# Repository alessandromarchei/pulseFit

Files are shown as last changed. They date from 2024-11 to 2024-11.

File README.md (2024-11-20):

# PulseFit - Wearable ECG Sensor and Fitness Tracker

**PulseFit** is a compact, energy-efficient, and wearable ECG monitoring device designed for sports and fitness enthusiasts. The project integrates cutting-edge hardware, efficient circuit design, and robust BLE communication to deliver real-time heart rate monitoring in an easy-to-use format. The device is ideal for users looking to track their cardiovascular health during physical activity.

---

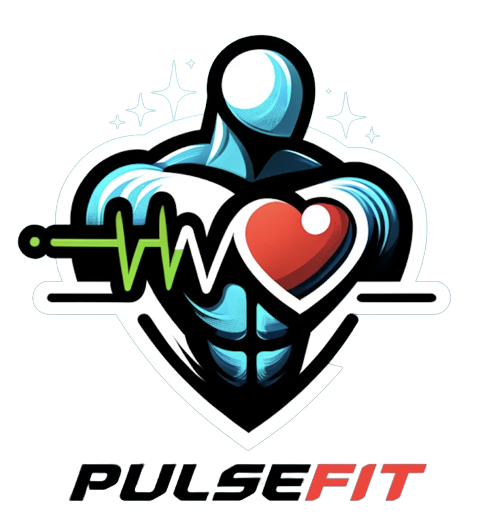
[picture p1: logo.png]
PulseFit


## **Table of Contents**
1. [Project Overview](#project-overview)
2. [Key Features](#key-features)
3. [System Overview](#system-overview)
4. [Hardware Components](#hardware-components)
   - [ECG Sensor](#ecg-sensor)
   - [Microcontroller](#microcontroller)
   - [Power Management](#power-management)
   - [Peripherals](#peripherals)
5. [PCB Design](#pcb-design)
6. [Power Consumption Analysis](#power-consumption-analysis)
7. [Bill of Materials (BOM) and Cost](#bill-of-materials-bom-and-cost)
8. [Usage Instructions](#usage-instructions)
9. [Development and Design History](#development-and-design-history)
10. [Contributors](#contributors)

---

## **Project Overview**
PulseFit is a wearable chest strap designed to monitor ECG signals and transmit data wirelessly to a connected device. The device leverages an **AD8232 ECG sensor** for accurate biopotential signal acquisition and a **CC2640 microcontroller** for data processing and BLE communication. With a battery life of over 40 hours, PulseFit balances functionality, portability, and cost, making it ideal for fitness tracking.

---

## **Key Features**
- **Advanced ECG Monitoring**: High-gain AD8232 sensor tailored for real-time heart rate analysis.
- **BLE Communication**: Integrates BLE 5.0 for seamless data transmission to smartphones or fitness devices.
- **Compact and Lightweight**: PCB dimensions of 5.1 x 2.39 cm, designed for user comfort.
- **Rechargeable and Sustainable**: LiPo battery with USB charging, providing up to 40 hours of use on a single charge.
- **User Feedback**: RGB and charge status LEDs for clear device status indication.
- **Robust Design**: Operates efficiently in extreme environments (-40°C to +85°C).

---

## **System Overview**
The PulseFit system includes the following subsystems:
1. **Signal Acquisition**:
   - Captures ECG signals using the AD8232 sensor.
   - Optimized for minimal interference and high signal integrity.
2. **Data Processing**:
   - Processes signals with the CC2640 ARM Cortex-M3 microcontroller.
   - Converts analog signals to digital values for BLE transmission.
3. **Power Management**:
   - Voltage regulator (**MAX1759EUB**) adapts battery voltage to 3.3V.
   - LiPo battery with USB recharging and thermal protection.
4. **User Interaction**:
   - RGB LED for operational feedback and Red/Green LEDs for charge status.
5. **Wireless Communication**:
   - A 2.4 GHz BLE antenna ensures efficient and reliable data transmission.

---

## **Hardware Components**
### **ECG Sensor**
- **Model**: AD8232
- **Purpose**: Captures biopotential signals with minimal interference.
- **Configuration**: "Next-to-Heart" mode for enhanced cardiac signal strength.
- **Specifications**:
  - Low supply current: 170µA
  - Shutdown mode: 40nA
  - Integrated right-leg drive amplifier
  - High CMRR: 80 dB
- **Advantages**: Compact design with minimal external components for noise reduction.

### **Microcontroller**
- **Model**: CC2640 (Texas Instruments)
- **Core**: ARM Cortex-M3 @ 48 MHz.
- **Features**:
  - Integrated BLE 5.0 controller.
  - Ultra-low power standby mode (1.5µA).
  - Analog-to-Digital Converter (ADC) for ECG signal processing.
- **I/O**:
  - Dedicated GPIO for RGB LEDs and ECG sensor control.
  - JTAG interface for debugging.

### **Power Management**
- **Battery**: LP402025 LiPo (150mAh).
- **Charger**: MCP73831 USB charger with constant-current/voltage control.
- **Voltage Regulator**: MAX1759EUB for stable 3.3V output.
- **LED Indicators**:
  - Red: Charging.
  - Green: Fully charged.

### **Peripherals**
- **Electrodes**: Gold-plated, dry electrodes for superior signal quality and durability.
- **Antenna**: 2.4 GHz patch antenna for BLE communication.
- **Buttons**: Reset button and power slide switch.

---

## **PCB Design**
### **Layout Highlights**
- **Dimensions**: 5.1 x 2.39 cm.
- **Component Placement**:
  - Antenna positioned for minimal interference.
  - ECG sensor placed close to the microcontroller for short signal paths.
  - Power components grouped together for efficient routing.
- **Routing**:
  - Trace width: 0.25 mm to minimize impedance.
  - Class 5C compliance for manufacturing standards.
- **Ground Plane**:
  - Provides noise shielding for critical components.

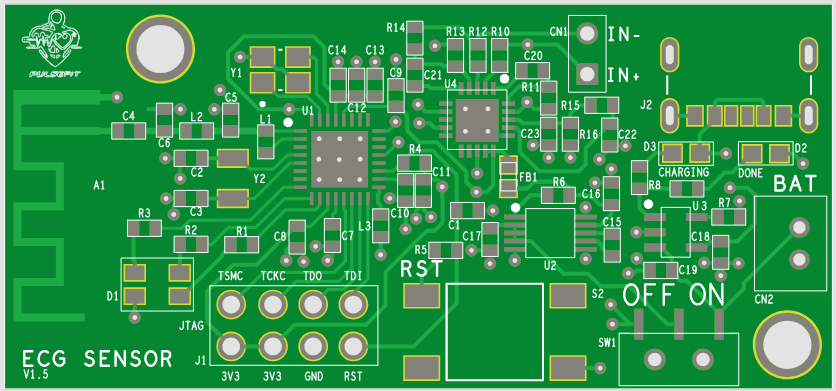
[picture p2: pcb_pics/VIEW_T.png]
Top View of the PCB

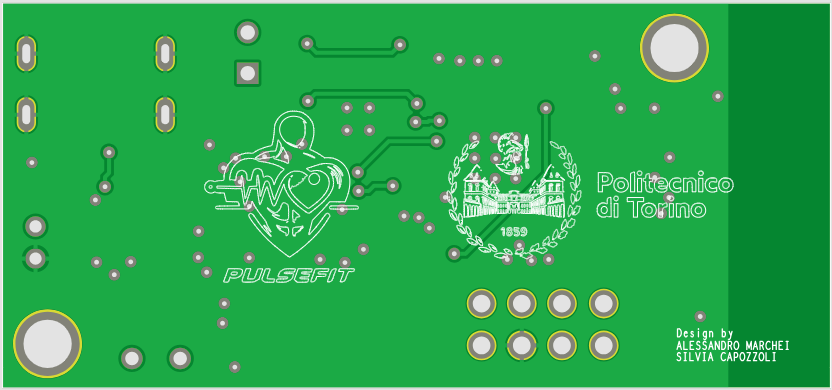
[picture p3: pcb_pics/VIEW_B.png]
Bottom View of the PCB


---

## **Power Consumption Analysis**
Average power consumption:
- **Microcontroller**: 3.02mA.
- **ECG Sensor**: 0.17mA.
- **RGB LEDs**: 0.51mA.
- **Estimated Battery Life**: ~40 hours (150mAh battery).

---

## **Bill of Materials (BOM) and Cost**
### **Cost Breakdown**
| Quantity | PCB (€) | Components (€) | Electrodes (€) | Stencil (€) | Total (€) |
|---|---|---|---|---|---|
| 1 | 38.83 | 30.58 | 18.20 | - | 87.61 |
| 10 | 6.84 | 24.52 | 18.20 | - | 49.56 |
| 100 | 1.80 | 19.38 | 18.20 | 0.33 | 39.71 |
| 1000 | 0.74 | 19.38 | 18.20 | 0.033 | 38.35 |

---

## **Usage Instructions**
1. **Setup**:
   - Charge the device via USB.
   - Attach the chest strap securely with electrodes in place.
2. **Operation**:
   - Power on using the slide switch.
   - Observe RGB LED indicators for device status.
   - Pair with a BLE-compatible device to monitor ECG data.
3. **Maintenance**:
   - Clean electrodes after use.
   - Recharge battery as needed.

In this project, the main files are the following:

- A **project** directory with 2 subfolders : 
	- "Temp" directory contains the entire project, both the Capture project and the Allegro board

	- "ORCAD_PERSONAL_LIBRARY" contains every .OLB for the schematic libraries, every footprint contained in the board and relative .psm in the subfolder "FOOTPRINTS" and every padstack (.pad) in the "PADSTACK" folder.

- The **REPORT** of the project (.pdf)

- The **BOM** containing every cost related to the device, with every price based on the purchase quantity (.xslx)

- The **video demo** of the project (.mp4)

- **Slides** of the video demo (.pdf)

---

## **Development and Design History**
### **Version Highlights**
- **v1.1**: Initial schematic and PCB design.
- **v1.2**: Introduced slide switch for improved usability.
- **v1.3**: Optimized electrode connectivity.
- **v1.4**: Improved component spacing and reduced manufacturing costs.
- **v1.5**: Added mounting holes for secure casing attachment.

---

## **Contributors**
- [Alessandro Marchei](https://github.com/alessandromarchei)
- Silvia Capozzoli

For full documentation and design files, please refer to the `docs` folder, which contains the 'pulsefit.pdf' for the entire report documenting the purpose and details of the entire project.

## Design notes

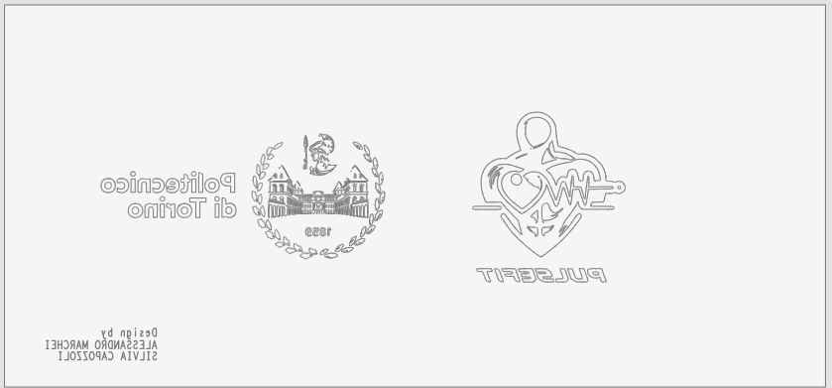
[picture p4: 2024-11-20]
pcb_pics/LEGEND_B.png

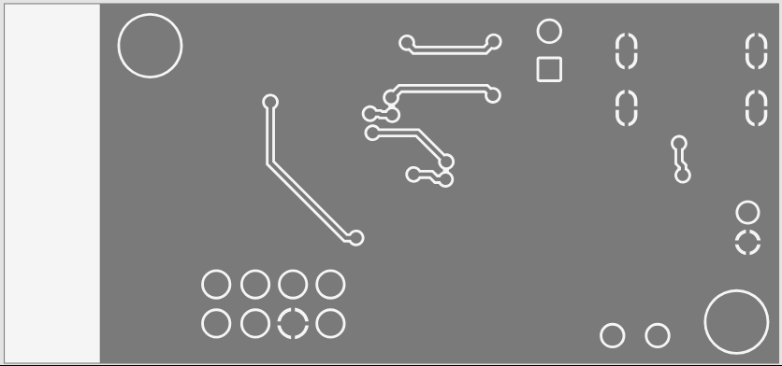
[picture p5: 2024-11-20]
pcb_pics/COPPER_B.png

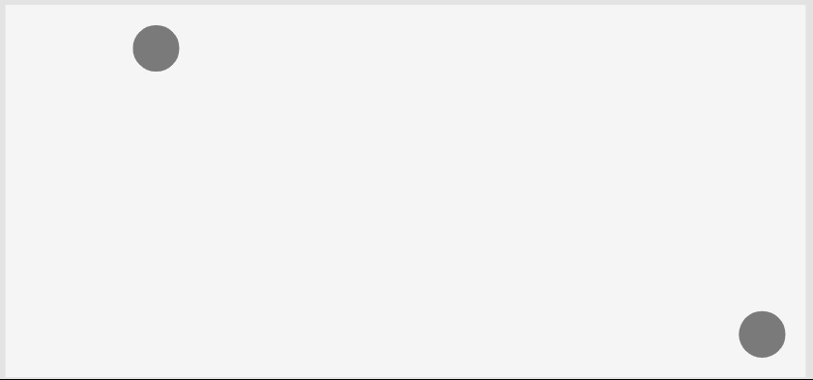
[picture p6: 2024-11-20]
pcb_pics/NON_PLATED_DRILL.png

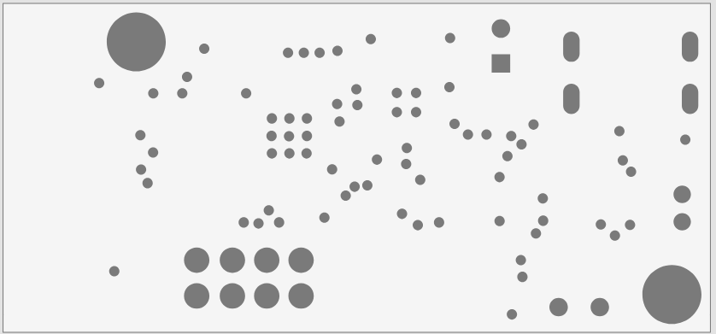
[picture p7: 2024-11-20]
pcb_pics/SMASK_B.png

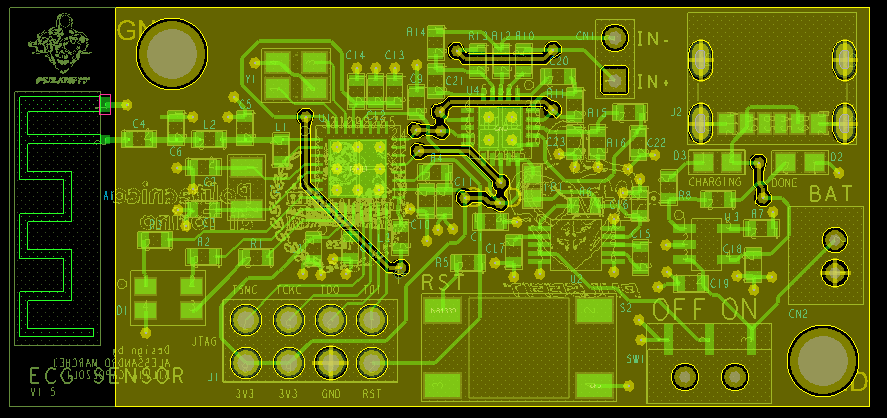
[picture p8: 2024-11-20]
pcb_pics/PCB_BOTTOM.png

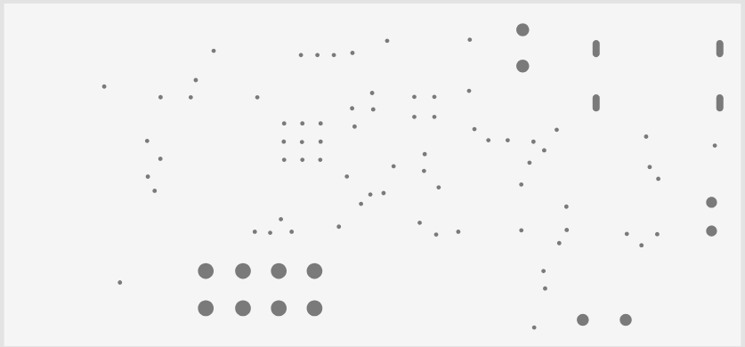
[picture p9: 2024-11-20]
pcb_pics/PLATED_DRILL.png

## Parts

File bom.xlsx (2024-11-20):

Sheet: 1
ITEM | QTY | REFERENCE | PART | COMPONENT | MOUNTING TYPE | MANUFACTURER | SUPPLIER | UNIT PRICE
1 | 1 | A1 | ANTENNA | / |  |  | /
2 | 1 | CN1 | 2x HEADER | 3-644456-2 | TH | TE Connectivity AMP Connectors | Digikey | 0.1800 €
3 | 1 | CN2 | JST-2P | B2B-PH-K-S | TH | JST Sales America Inc. | Digikey | 0.1700 €
4 | 3 | C2,C3,C4 | 12 pF | 600S120GT250XT | SMD | Amercian Technical Ceramics | Digikey | 1.0500 €
5 | 2 | C5,C6 | 1.2 pF | QSCP251Q1R2B1GV001T | SMD | Johanson Technology | Digikey | 0.2000 €
6 | 1 | C7 | 1 uF | CL10B105KA8NNNC | SMD | Samsung Electro-Mechanics | Digikey | 0.0900 €
7 | 5 | C1,C8,C9,C11,C13,C14 | 100 nF | CL10B104KA8NNNC | SMD | Samsung Electro-Mechanics | Digikey | 0.0900 €
8 | 3 | C10,C12,C16 C17 | 10 uF | CL10A106MA8NRNC | SMD | Samsung Electro-Mechanics | Digikey | 0.2400 €
9 | 1 | C15 | 0.33 uF | CL10B334KA8VPNC | SMD | Samsung Electro-Mechanics | Digikey | 0.1300 €
10 | 2 | C18,C19 | 4.7uF | CL10A475MA8NQNC | SMD | Samsung Electro-Mechanics | Digikey | 0.2500 €
11 | 1 | C20 | 0.22uF | CC0603KRX7R9BB224 | SMD | YAGEO | Digikey | 0.2600 €
12 | 1 | C21 | 1nF | AC0603JRNPO0BN102 | SMD | YAGEO | Digikey | 0.1500 €
13 | 2 | C22,C23 | 0.1uF | CC0603MRX7R9BB104 | SMD | YAGEO | Digikey | 0.0900 €
14 | 1 | D1 | RGB | XZM2CRKM2DGFBB45SCCB | SMD | SunLED | Digikey | 0.9300 €
15 | 2 | D2,D3 | LED | LTST-S270KGKT | SMD | Lite-On Inc. | Digikey | 0.2200 €
16 | 1 | J1 | 4X2 MALE HEADER | 61300821121 | TH | Würth Elektronik | Digikey | 0.6400 €
17 | 1 | J2 | USB CONNECTOR | UJC-HP-3-SMT-TR | SMD | CUI Devices | Digikey | 0.9100 €
18 | 1 | L1 | 15 nH | BSPQ0006030415NH00 | SMD | Pulse Electronics | Digikey | 0.1200 €
19 | 1 | L2 | 2 nH | L-14W2N0CV4E | SMD | Johanson Technology Inc. | Digikey | 0.2100 €
20 | 1 | L3 | 10 uH | LQM18DH100M70L | SMD | Murata Electronics | Digikey | 0.2300 €
21 | 2 | R1,R2 | 100 | RC0603JR-07100RL | SMD | YAGEO | Digikey | 0.0900 €
22 | 1 | R3 | 270 | RC0603FR-07270RL | SMD | YAGEO | Digikey | 0.0900 €
23 | 1 | R4 | 10k | RMCF0603FT10K0 | SMD | Stackpole Electronics Inc | Digikey | 0.0900 €
24 | 1 | R5 | 330 | RC0603JR-13330RL | SMD | YAGEO | Digikey | 0.0900 €
25 | 1 | R6 | 100 k | RMCF0603FT100K | SMD | Stackpole Electronics Inc | Digikey | 0.0900 €
26 | 1 | R7 | 8.2 k | RMCF0603FT8K20 | SMD | Stackpole Electronics Inc | Digikey | 0.0900 €
27 | 2 | R8,R9 | 150 | RT0603FRE07150RL | SMD | YAGEO | Digikey | 0.0900 €
28 | 2 | R10,R12 | 180k | ERA-8AEB184V | SMD | Panasonic Electronic Components | Digikey | 0.5400 €
29 | 5 | R11,R13,R14,R15,R16 | 10M | RC0603FR-1310ML | SMD | YAGEO | Digikey | 0.0900 €
30 | 1 | S1 | SPDT | AYZ0102AGRLC | TH | C&K | Digikey | 1.1400 €
31 | 1 | S2 | BUTTON | FSM2JSMA | SMD | TE Connectivity ALCOSWITCH Switches | Digikey | 0.2500 €
32 | 1 | U1 | CC2640R2LRHBR | CC2640R2LRHBR | SMD | Texas Instruments | Digikey | 4.0100 €
33 | 1 | U2 | MAX1759 | MAX1759EUB+ | SMD | Analog Devices Inc./Maxim Integrated | Digikey | 6.8800 €
34 | 1 | U3 | MCP73831 | MCP73831T-2ACI/OT | SMD | Microchip Technology | Digikey | 0.6900 €
35 | 1 | U4 | ECG SENSOR | AD8233 | SMD | Analog Devices Inc. | Digikey | 4.2500 €
36 | 1 | Y1 | 24 MHz | TSX-3225_240000MF20X-AC1 | SMD | Epson | Digikey | 0.3500 €
37 | 1 | Y2 | 32.76 KHz | FC-135R_327680KA-AG1 | SMD | Epson | Digikey | 0.6400 €
38 | 1 | FB1 | 1.5 Kohm @ 100 MHz | BLM18HE152SN1D | SMD | Murata Electronics | Digikey | 0.1700 €
 | TOTAL |  |  |  |  |  |  | 30.5800 €

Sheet: 10
ITEM | QTY | REFERENCE | PART | COMPONENT | MOUNTING TYPE | MANUFACTURER | SUPPLIER | UNIT PRICE
1 | 1 | A1 | ANTENNA | / |  |  | /
2 | 1 | CN1 | 2x HEADER | 3-644456-2 | TH | TE Connectivity AMP Connectors | Digikey | 0.1560 €
3 | 1 | CN2 | JST-2P | B2B-PH-K-S | TH | JST Sales America Inc. | Digikey | 0.1340 €
4 | 3 | C2,C3,C4 | 12 pF | 600S120GT250XT | SMD | Amercian Technical Ceramics | Digikey | 0.7880 €
5 | 2 | C5,C6 | 1.2 pF | QSCP251Q1R2B1GV001T | SMD | Johanson Technology | Digikey | 0.1320 €
6 | 1 | C7 | 1 uF | CL10B105KA8NNNC | SMD | Samsung Electro-Mechanics | Digikey | 0.0360 €
7 | 5 | C1,C8,C9,C11,C13,C14 | 100 nF | CL10B104KA8NNNC | SMD | Samsung Electro-Mechanics | Digikey | 0.0220 €
8 | 3 | C10,C12,C16 C17 | 10 uF | CL10A106MA8NRNC | SMD | Samsung Electro-Mechanics | Digikey | 0.1550 €
9 | 1 | C15 | 0.33 uF | CL10B334KA8VPNC | SMD | Samsung Electro-Mechanics | Digikey | 0.0880 €
10 | 2 | C18,C19 | 4.7uF | CL10A475MA8NQNC | SMD | Samsung Electro-Mechanics | Digikey | 0.1610 €
11 | 1 | C20 | 0.22uF | CC0603KRX7R9BB224 | SMD | YAGEO | Digikey | 0.1660 €
12 | 1 | C21 | 1nF | AC0603JRNPO0BN102 | SMD | YAGEO | Digikey | 0.1010 €
13 | 2 | C22,C23 | 0.1uF | CC0603MRX7R9BB104 | SMD | YAGEO | Digikey | 0.0410 €
14 | 1 | D1 | RGB | XZM2CRKM2DGFBB45SCCB | SMD | SunLED | Digikey | 0.6060 €
15 | 2 | D2,D3 | LED | LTST-S270KGKT | SMD | Lite-On Inc. | Digikey | 0.1210 €
16 | 1 | J1 | 4X2 MALE HEADER | 61300821121 | TH | Würth Elektronik | Digikey | 0.5410 €
17 | 1 | J2 | USB CONNECTOR | UJC-HP-3-SMT-TR | SMD | CUI Devices | Digikey | 0.7610 €
18 | 1 | L1 | 15 nH | BSPQ0006030415NH00 | SMD | Pulse Electronics | Digikey | 0.0960 €
19 | 1 | L2 | 2 nH | L-14W2N0CV4E | SMD | Johanson Technology Inc. | Digikey | 0.1670 €
20 | 1 | L3 | 10 uH | LQM18DH100M70L | SMD | Murata Electronics | Digikey | 0.1820 €
21 | 2 | R1,R2 | 100 | RC0603JR-07100RL | SMD | YAGEO | Digikey | 0.0140 €
22 | 1 | R3 | 270 | RC0603FR-07270RL | SMD | YAGEO | Digikey | 0.0170 €
23 | 1 | R4 | 10k | RMCF0603FT10K0 | SMD | Stackpole Electronics Inc | Digikey | 0.0140 €
24 | 1 | R5 | 330 | RC0603JR-13330RL | SMD | YAGEO | Digikey | 0.0140 €
25 | 1 | R6 | 100 k | RMCF0603FT100K | SMD | Stackpole Electronics Inc | Digikey | 0.0140 €
26 | 1 | R7 | 8.2 k | RMCF0603FT8K20 | SMD | Stackpole Electronics Inc | Digikey | 0.0140 €
27 | 2 | R8,R9 | 150 | RT0603FRE07150RL | SMD | YAGEO | Digikey | 0.0490 €
28 | 2 | R10,R12 | 180k | ERA-8AEB184V | SMD | Panasonic Electronic Components | Digikey | 0.3620 €
29 | 5 | R11,R13,R14,R15,R16 | 10M | RC0603FR-1310ML | SMD | YAGEO | Digikey | 0.0170 €
30 | 1 | S1 | SPDT | AYZ0102AGRLC | TH | C&K | Digikey | 1.1010 €
31 | 1 | S2 | BUTTON | FSM2JSMA | SMD | TE Connectivity ALCOSWITCH Switches | Digikey | 0.2370 €
32 | 1 | U1 | CC2640R2LRHBR | CC2640R2LRHBR | SMD | Texas Instruments | Digikey | 3.5790 €
33 | 1 | U2 | MAX1759 | MAX1759EUB+ | SMD | Analog Devices Inc./Maxim Integrated | Digikey | 6.2170 €
34 | 1 | U3 | MCP73831 | MCP73831T-2ACI/OT | SMD | Microchip Technology | Digikey | 0.6900 €
35 | 1 | U4 | ECG SENSOR | AD8233 | SMD | Analog Devices Inc. | Digikey | 3.8140 €
36 | 1 | Y1 | 24 MHz | TSX-3225_240000MF20X-AC1 | SMD | Epson | Digikey | 0.3230 €
37 | 1 | Y2 | 32.76 KHz | FC-135R_327680KA-AG1 | SMD | Epson | Digikey | 0.5300 €
38 | 1 | FB1 | 1.5 Kohm @ 100 MHz | BLM18HE152SN1D | SMD | Murata Electronics | Digikey | 0.1400 €
 | TOTAL |  |  |  |  |  |  | 24.5220 €

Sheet: 100
ITEM | QTY | REFERENCE | PART | COMPONENT | MOUNTING TYPE | MANUFACTURER | SUPPLIER | UNIT PRICE
1 | 1 | A1 | ANTENNA | / |  |  | /
2 | 1 | CN1 | 2x HEADER | 3-644456-2 | TH | TE Connectivity AMP Connectors | Digikey | 0.1420 €
3 | 1 | CN2 | JST-2P | B2B-PH-K-S | TH | JST Sales America Inc. | Digikey | 0.0992 €
4 | 3 | C2,C3,C4 | 12 pF | 600S120GT250XT | SMD | Amercian Technical Ceramics | Digikey | 0.5887 €
5 | 2 | C5,C6 | 1.2 pF | QSCP251Q1R2B1GV001T | SMD | Johanson Technology | Digikey | 0.0749 €
6 | 1 | C7 | 1 uF | CL10B105KA8NNNC | SMD | Samsung Electro-Mechanics | Digikey | 0.0160 €
7 | 5 | C1,C8,C9,C11,C13,C14 | 100 nF | CL10B104KA8NNNC | SMD | Samsung Electro-Mechanics | Digikey | 0.0096 €
8 | 3 | C10,C12,C16 C17 | 10 uF | CL10A106MA8NRNC | SMD | Samsung Electro-Mechanics | Digikey | 0.0881 €
9 | 1 | C15 | 0.33 uF | CL10B334KA8VPNC | SMD | Samsung Electro-Mechanics | Digikey | 0.0411 €
10 | 2 | C18,C19 | 4.7uF | CL10A475MA8NQNC | SMD | Samsung Electro-Mechanics | Digikey | 0.0916 €
11 | 1 | C20 | 0.22uF | CC0603KRX7R9BB224 | SMD | YAGEO | Digikey | 0.0942 €
12 | 1 | C21 | 1nF | AC0603JRNPO0BN102 | SMD | YAGEO | Digikey | 0.0476 €
13 | 2 | C22,C23 | 0.1uF | CC0603MRX7R9BB104 | SMD | YAGEO | Digikey | 0.0184 €
14 | 1 | D1 | RGB | XZM2CRKM2DGFBB45SCCB | SMD | SunLED | Digikey | 0.3971 €
15 | 2 | D2,D3 | LED | LTST-S270KGKT | SMD | Lite-On Inc. | Digikey | 0.0563 €
16 | 1 | J1 | 4X2 MALE HEADER | 61300821121 | TH | Würth Elektronik | Digikey | 0.3419 €
17 | 1 | J2 | USB CONNECTOR | UJC-HP-3-SMT-TR | SMD | CUI Devices | Digikey | 0.6836 €
18 | 1 | L1 | 15 nH | BSPQ0006030415NH00 | SMD | Pulse Electronics | Digikey | 0.0676 €
19 | 1 | L2 | 2 nH | L-14W2N0CV4E | SMD | Johanson Technology Inc. | Digikey | 0.1244 €
20 | 1 | L3 | 10 uH | LQM18DH100M70L | SMD | Murata Electronics | Digikey | 0.1362 €
21 | 2 | R1,R2 | 100 | RC0603JR-07100RL | SMD | YAGEO | Digikey | 0.0068 €
22 | 1 | R3 | 270 | RC0603FR-07270RL | SMD | YAGEO | Digikey | 0.0086 €
23 | 1 | R4 | 10k | RMCF0603FT10K0 | SMD | Stackpole Electronics Inc | Digikey | 0.0068 €
24 | 1 | R5 | 330 | RC0603JR-13330RL | SMD | YAGEO | Digikey | 0.0068 €
25 | 1 | R6 | 100 k | RMCF0603FT100K | SMD | Stackpole Electronics Inc | Digikey | 0.0068 €
26 | 1 | R7 | 8.2 k | RMCF0603FT8K20 | SMD | Stackpole Electronics Inc | Digikey | 0.0068 €
27 | 2 | R8,R9 | 150 | RT0603FRE07150RL | SMD | YAGEO | Digikey | 0.0199 €
28 | 2 | R10,R12 | 180k | ERA-8AEB184V | SMD | Panasonic Electronic Components | Digikey | 0.1905 €
29 | 5 | R11,R13,R14,R15,R16 | 10M | RC0603FR-1310ML | SMD | YAGEO | Digikey | 0.0085 €
30 | 1 | S1 | SPDT | AYZ0102AGRLC | TH | C&K | Digikey | 0.8947 €
31 | 1 | S2 | BUTTON | FSM2JSMA | SMD | TE Connectivity ALCOSWITCH Switches | Digikey | 0.2032 €
32 | 1 | U1 | CC2640R2LRHBR | CC2640R2LRHBR | SMD | Texas Instruments | Digikey | 2.9353 €
33 | 1 | U2 | MAX1759 | MAX1759EUB+ | SMD | Analog Devices Inc./Maxim Integrated | Digikey | 5.1466 €
34 | 1 | U3 | MCP73831 | MCP73831T-2ACI/OT | SMD | Microchip Technology | Digikey | 0.5584 €
35 | 1 | U4 | ECG SENSOR | AD8233 | SMD | Analog Devices Inc. | Digikey | 3.6050 €
36 | 1 | Y1 | 24 MHz | TSX-3225_240000MF20X-AC1 | SMD | Epson | Digikey | 0.2578 €
37 | 1 | Y2 | 32.76 KHz | FC-135R_327680KA-AG1 | SMD | Epson | Digikey | 0.4236 €
38 | 1 | FB1 | 1.5 Kohm @ 100 MHz | BLM18HE152SN1D | SMD | Murata Electronics | Digikey | 0.0900 €
 | TOTAL |  |  |  |  |  |  | 19.3790 €

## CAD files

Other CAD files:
project/ORCAD_PERSONAL_LIBRARY/FOOTPRINTS/0603_c.psm
project/ORCAD_PERSONAL_LIBRARY/FOOTPRINTS/0603_l.psm
project/ORCAD_PERSONAL_LIBRARY/FOOTPRINTS/0603_r.psm
project/ORCAD_PERSONAL_LIBRARY/FOOTPRINTS/BUTTON_SMD.psm
project/ORCAD_PERSONAL_LIBRARY/FOOTPRINTS/CC2640.psm
project/ORCAD_PERSONAL_LIBRARY/FOOTPRINTS/CONN2.psm
project/ORCAD_PERSONAL_LIBRARY/FOOTPRINTS/HEADER2.psm
project/ORCAD_PERSONAL_LIBRARY/FOOTPRINTS/JTAG_conn.psm
project/ORCAD_PERSONAL_LIBRARY/FOOTPRINTS/MAX1759.psm
project/ORCAD_PERSONAL_LIBRARY/FOOTPRINTS/MCP73831.psm
project/ORCAD_PERSONAL_LIBRARY/FOOTPRINTS/MICRO_USB.psm
project/ORCAD_PERSONAL_LIBRARY/FOOTPRINTS/PB.psm
project/ORCAD_PERSONAL_LIBRARY/FOOTPRINTS/PB_SMD.psm
project/ORCAD_PERSONAL_LIBRARY/FOOTPRINTS/PB_sw.psm
project/ORCAD_PERSONAL_LIBRARY/FOOTPRINTS/RED_LED.psm
project/ORCAD_PERSONAL_LIBRARY/FOOTPRINTS/RGB.psm
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

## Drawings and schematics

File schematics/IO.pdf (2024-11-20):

## RGB LED

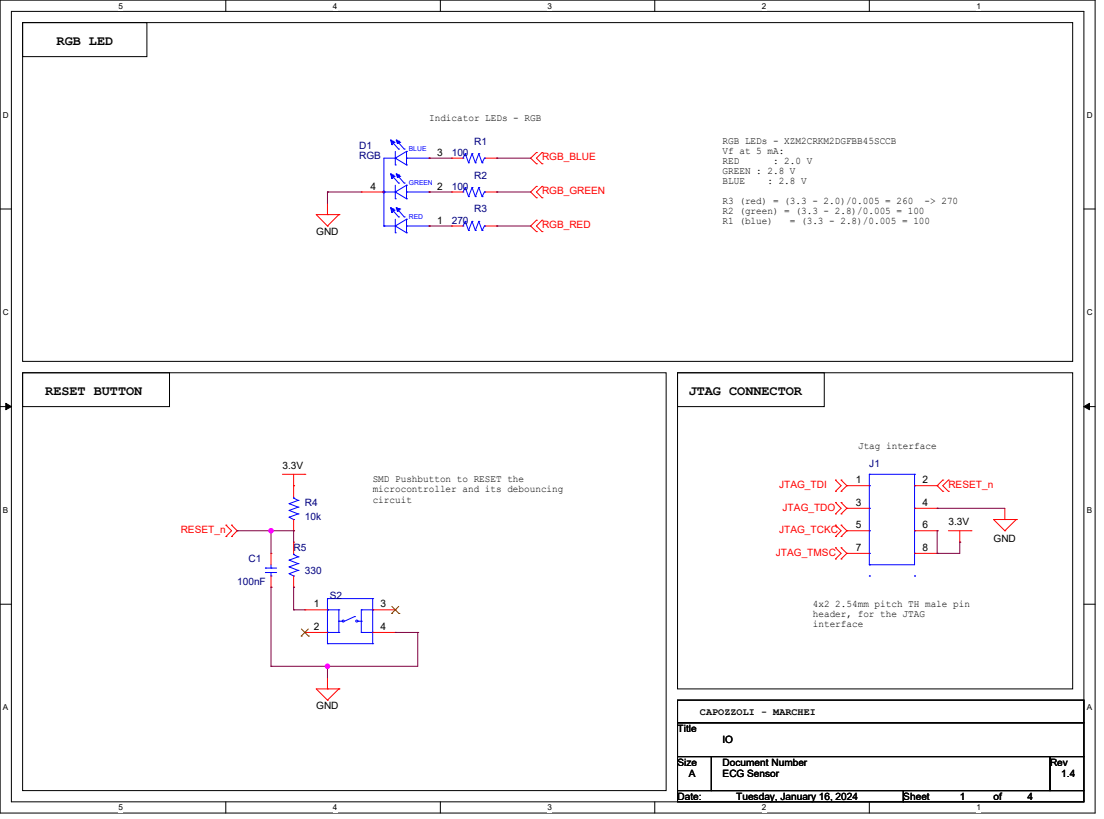
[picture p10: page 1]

SMD Pushbutton to RESET the
microcontroller and its debouncing
circuit

4x2 2.54mm pitch TH male pin
header, for the JTAG
interface

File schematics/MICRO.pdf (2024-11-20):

### VDDR Decoupling Capacitors

### CRYSTAL OSCILLATORS

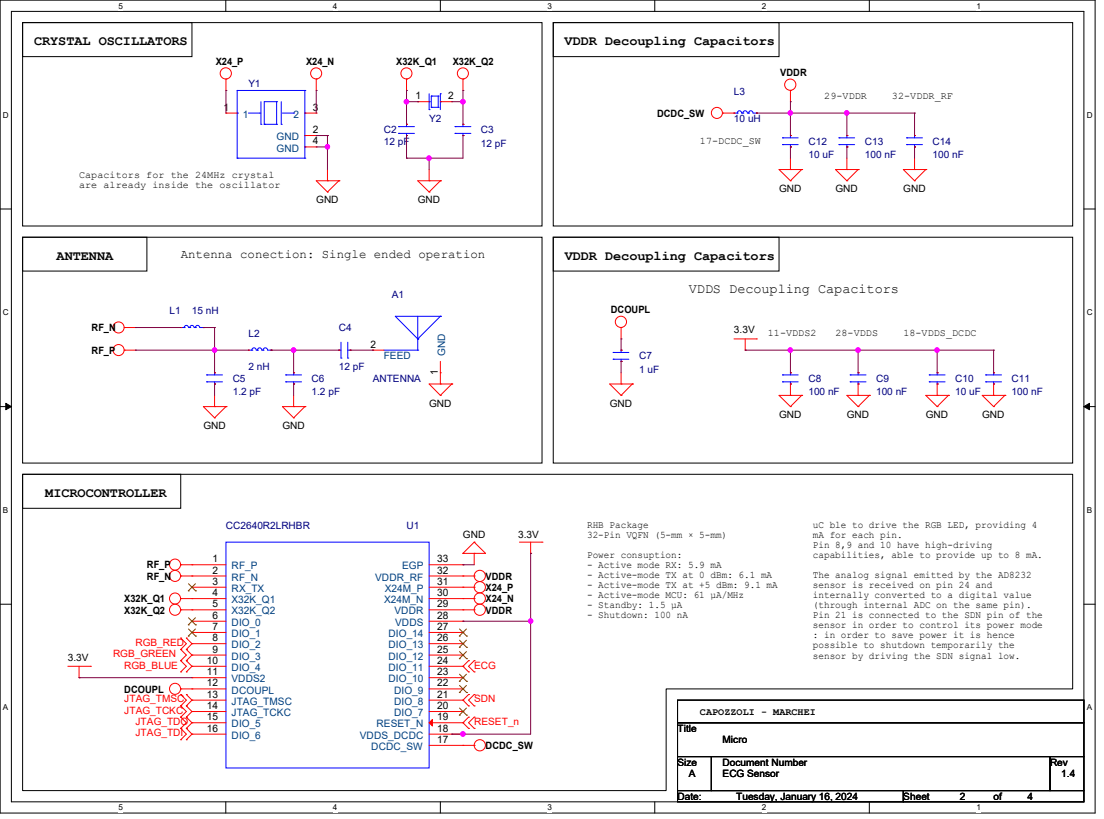
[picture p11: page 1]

Capacitors for the 24MHz crystal
are already inside the oscillator

Antenna conection: Single ended operation

RHB Package
32-Pin VQFN (5-mm × 5-mm)
Power consuption:
- Active mode RX: 5.9 mA
- Active-mode TX at 0 dBm: 6.1 mA
- Active-mode TX at +5 dBm: 9.1 mA
- Active-mode MCU: 61 µA/MHz
- Standby: 1.5 µA
- Shutdown: 100 nA

uC ble to drive the RGB LED, providing 4
mA for each pin.
Pin 8,9 and 10 have high-driving
capabilities, able to provide up to 8 mA.
The analog signal emitted by the AD8232
sensor is received on pin 24 and
internally converted to a digital value
(through internal ADC on the same pin).
Pin 21 is connected to the SDN pin of the
sensor in order to control its power mode
: in order to save power it is hence
possible to shutdown temporarily the
sensor by driving the SDN signal low.

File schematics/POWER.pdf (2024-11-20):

### USB-C CONNECTOR

### BATTERY CHARGER

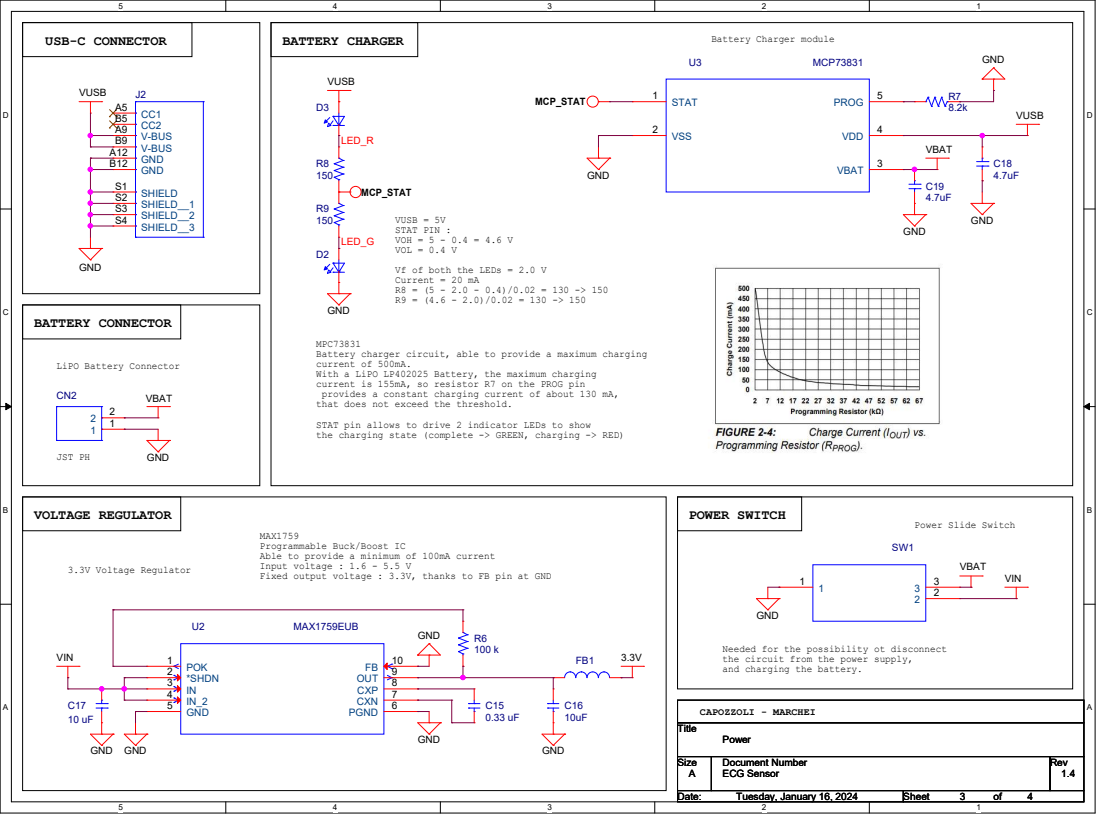
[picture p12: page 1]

BATTERY CONNECTOR JST PH

MPC73831
Battery charger circuit, able to provide a maximum charging
current of 500mA.
With a LiPO LP402025 Battery, the maximum charging
current is 155mA, so resistor R7 on the PROG pin
provides a constant charging current of about 130 mA,
that does not exceed the threshold.
STAT pin allows to drive 2 indicator LEDs to show
the charging state (complete -> GREEN, charging -> RED)

MAX1759
Programmable Buck/Boost IC
Able to provide a minimum of 100mA current
Input voltage : 1.6 - 5.5 V
Fixed output voltage : 3.3V, thanks to FB pin at GND

Needed for the possibility ot disconnect
the circuit from the power supply,
and charging the battery.

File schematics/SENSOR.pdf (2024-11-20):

ECG SENSOR | ELECTRODES

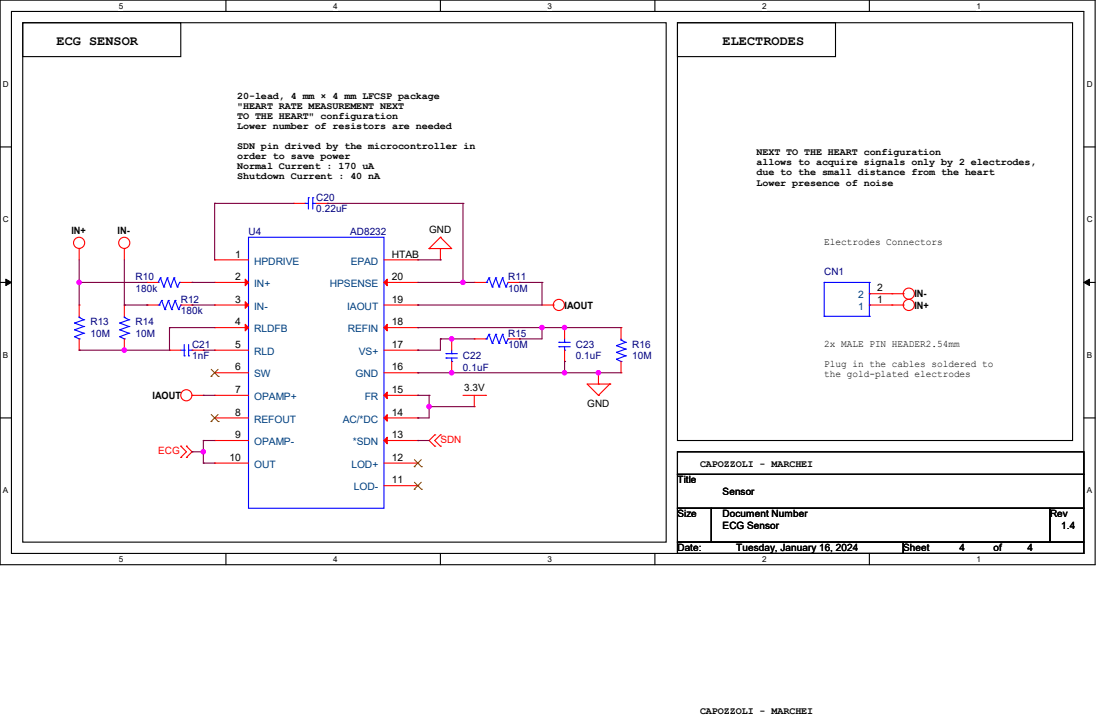
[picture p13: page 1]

20-lead, 4 mm × 4 mm LFCSP package
"HEART RATE MEASUREMENT NEXT
TO THE HEART" configuration
Lower number of resistors are needed
SDN pin drived by the microcontroller in
order to save power
Normal Current : 170 uA
Shutdown Current : 40 nA

NEXT TO THE HEART configuration
allows to acquire signals only by 2 electrodes,
due to the small distance from the heart
Lower presence of noise

2x MALE PIN HEADER2.54mm
Plug in the cables soldered to
the gold-plated electrodes

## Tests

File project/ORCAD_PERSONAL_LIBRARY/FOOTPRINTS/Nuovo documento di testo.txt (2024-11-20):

C:\Cadence\SPB_17.2\tools\bin\allegro.exe

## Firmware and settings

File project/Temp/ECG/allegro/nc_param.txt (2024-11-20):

INTEGER-PLACES         3
DECIMAL-PLACES         3
X-OFFSET               0.000000
Y-OFFSET               0.000000
FEEDRATE               1
COORDINATES            ABSOLUTE
OUTPUT-UNITS           METRIC
TOOL-ORDER             INCREASING
REPEAT-CODES           NO
SUPPRESS-LEAD-ZEROES   YES
SUPPRESS-TRAIL-ZEROES  NO
SUPPRESS-EQUAL         NO
TOOL-SELECT            YES
OPTIMIZE_DRILLING      NO
ENHANCED_EXCELLON      YES
TAPE-FILE              C:/Temp/ECG/allegro/ECG_v5.drl
HEADER                 none
LEADER                 12
CODE                   ASCII
SEPARATE               YES
SEPARATE-ROUTING       NO
DRILLING               LAYER-PAIR
BACKDRILL              NO
CAVITY                 NO
COUNTER                NO
TOLERANCE_DRILL        NO
TOLERANCE_TRAVEL       NO
TOOL_SIZE              NO
ROTATION               NO
NON_STANDARD           NO
TOTAL_DRILL            NO
SEPARATE_SLOT          NO
SUPPRESS_TOLERANCE     NO
SUPPRESS_TOOLSIZE      NO
SUPPRESS_ROTATION      NO
